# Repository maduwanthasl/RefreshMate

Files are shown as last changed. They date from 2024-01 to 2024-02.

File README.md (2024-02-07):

# Refreshmate: Automated Air Renewal and Freshener System for Public Toilets

## Overview
 🌬️ Introducing Refreshmate: Automated air renewal for public toilets. Gas sensors, microcontrollers, and a smart power mix tackle unpleasant odors, circulate fresh air, and add a pleasant aroma. Easy install, eco-friendly, optimized for performance. Completion accomplished for the Engineering Design Project in In21-S2-EN1190. 🚀

## Introduction:

- Refreshmate: Innovative project for automated air renewal and freshener in public toilets.
- Core components: Gas sensor, exhaust fan, and air freshener, powered by both electricity and batteries.
- Primary goal: Autonomously detect and eliminate unpleasant odors, improving air quality.
- Meticulous layout procedure: Careful component selection, testing, and systematic generation for optimal performance.
- Final product features: Easy installation, operation, and maintenance with minimal energy consumption, emphasizing environmental friendliness.

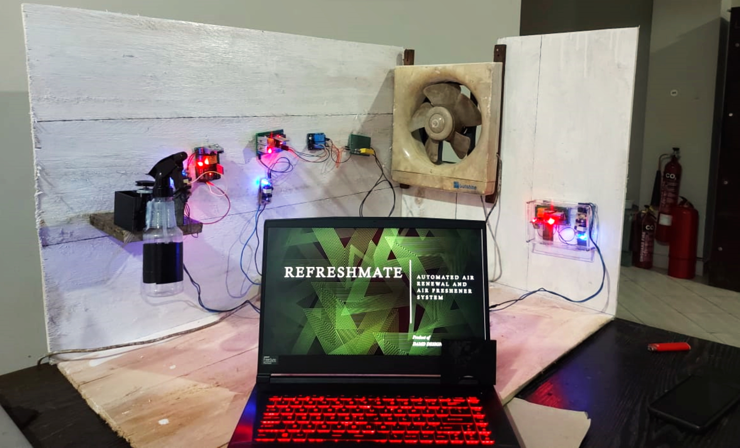
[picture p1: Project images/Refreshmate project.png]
Project Image


## How Rereshmate Works:

[Refreshmate Project Explain](https://github.com/maduwanthasl/RefreshMate/assets/107339150/9a8a3949-62f4-4360-bf2a-769d5a35e4b5)

**Modules:**
- We utilize three primary modules: the sensor module, the air freshener module, and the fan module.

**Gas Sensor Reading:**
- The gas sensor reads the air quality value in the restroom environment.

**ATTiny85 Processing:**
- The ATTiny85 microcontroller (in the sensor module) processes the data based on the air quality value.

**Data Transmission via HC-05 Bluetooth Module:**
- Using the HC-05 Bluetooth module, the processed data is transmitted to the air freshener and fan modules.

**ESP01 Module Data Processing:**
- The ESP01 modules in the air freshener and fan modules receive and process the transmitted data.

**Exhaust Fan Operation:**
- The exhaust fan is activated to expel dirty air rapidly in response to the processed data.

**Air Freshener Activation:**
- After a brief delay, the air freshener module is triggered, releasing a pleasant aroma into the restroom.

## Why I Chose These Components:

- Advanced Gas Sensing: Refreshmate employs a cutting-edge MQ135 gas sensor, swiftly identifying NH3 (ammonia) and demonstrating sensitivity to various other gases in the restroom environment. [Read datasheet](https://github.com/maduwanthasl/RefreshMate/blob/main/Datasheets/SNS-MQ135.pdf)
- Intelligent Microcontroller Control: The system strategically utilizes the compact ATTiny85 microcontroller for processing gas sensor data. The choice of ATTiny85, with its compact size and 8 pins, aligns seamlessly with project guidelines, allowing for a reduction in product size and cost. [Read datasheet](https://github.com/maduwanthasl/RefreshMate/blob/main/Datasheets/Atmel-2586-AVR-8-bit-Microcontroller-ATtiny25-ATtiny45-ATtiny85_Datasheet.pdf)
- Selection of ESP01 Module: To the air freshener module and fan module, the ESP01 Tiny Arduino-based module is seamlessly integrated. This compact and cost-effective module not only aligns with the project's space and budget considerations but also lays the foundation for future enhancements. The ESP01 facilitates the potential integration of server-based data transmission, allowing users to monitor and analyze air quality data remotely. Furthermore, the inclusion of WiFi capabilities opens the door to user-friendly features, enabling remote on/off control via WiFi, enhancing the overall accessibility and functionality of the Refreshmate system.[Read datasheet](https://github.com/maduwanthasl/RefreshMate/blob/main/Datasheets/esp01.pdf)
- Selection of HC-05 Bluetooth Module: I chose the HC-05 Bluetooth module for all modules due to its user-friendly attributes, including a small number of pins and ease of control.[Read datasheet](https://github.com/maduwanthasl/RefreshMate/blob/main/Datasheets/HC-05%20Datasheet.pdf)

## What I Did in This Project:
🛠️ During this project, I was responsible for:

- Defining clear objectives for Refreshmate, outlining the goals and desired outcomes.
- Conducting thorough research and planning to understand the requirements and challenges of automated air renewal in public toilets.
- Selecting appropriate components based on performance, compatibility, and cost considerations.
- Performing simulations in Proteus to validate the functionality and performance of the system before implementation.
- Testing individual components and subsystems to ensure functionality and reliability.
- Designing PCBs using Altium Designer for efficient integration and layout of electronic components.
- Creating enclosure designs in SolidWorks to house the electronic components securely and aesthetically.
- Testing the system with Arduino Uno microcontroller to verify compatibility and functionality.
- Soldering electronic components onto PCBs to assemble the hardware modules.
- Conducting rigorous testing of PCBs to identify and rectify any issues or defects.
- Implementing improvements based on testing results and feedback to enhance system performance and reliability.
- Finalizing the design and configuration of Refreshmate for deployment in real-world settings.
- Testing the system with prototype boards to evaluate performance under realistic conditions.
- Designing circuit diagrams to document the electrical connections and configurations of the system.
- Demonstrating the functionality of Refreshmate using Arduino Uno microcontroller for validation and verification.
- Testing and debugging the system to address any issues or errors and ensure smooth operation.

## Block diagram of systems
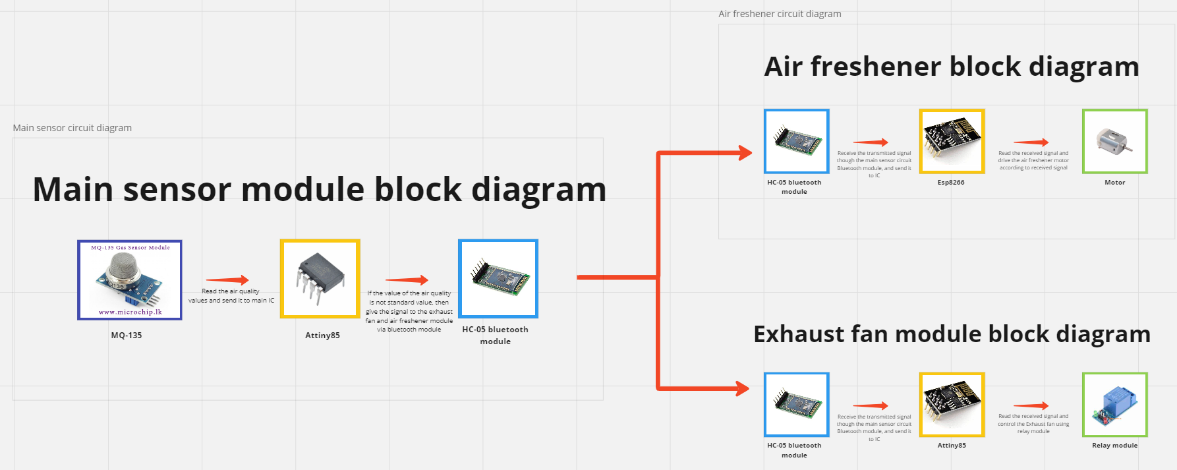
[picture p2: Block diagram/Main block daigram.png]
Block diagram


## Submodules, Circuits, and Tasks:

1. **Sensor Module:**
   - The sensor module is responsible for reading data from the environment to assess air quality.

2. **Air Freshener Module:**
   - Upon receiving data, the air freshener module activates with a slight delay. It adjusts the release of air freshener liquid based on the detected level of pollutants. Higher levels of pollutants trigger a stronger release of the air freshener.

3. **Fan Module:**
   - The fan module responds to received data by activating the fan. It adjusts the fan speed based on the detected level of pollutants. Higher levels of pollutants result in a higher fan speed, while lower levels lead to a slower fan speed.

## Hardware Specifications

| Component | Specification |
|---|---|
| Gas Sensor | MQ135 |
| Exhaust Fan | AC Cooling Fan 8025 |
| Air Freshener | Airwick Air Freshener Spray 475ml |
| DC Power Supply | 3.7V LiPo Batteries (x3) and 9V Batteries |
| AC Power Supply | SMPS Power supply 12V |
| Bluetooth Modules | HC-05 (x6) |
| Microcontroller | ATTiny85 |
| ESP Modules | ESP01 (x2) |
| Motor | N/A |
| Relay Modules | 9V Relay Modules (x2) ,Two chaneel relay module |
| Heat Sinks | Heat Sinks (x4) |
| Other Components | Resistors, Capacitors, LEDs, Connecting Wires, Diodes, Plug Coverings, and more |

## Software Specifications

- Solidworks
- Altium Designer
- Proteus
- Arduino IDE

## PCB Designs

### Sensor module

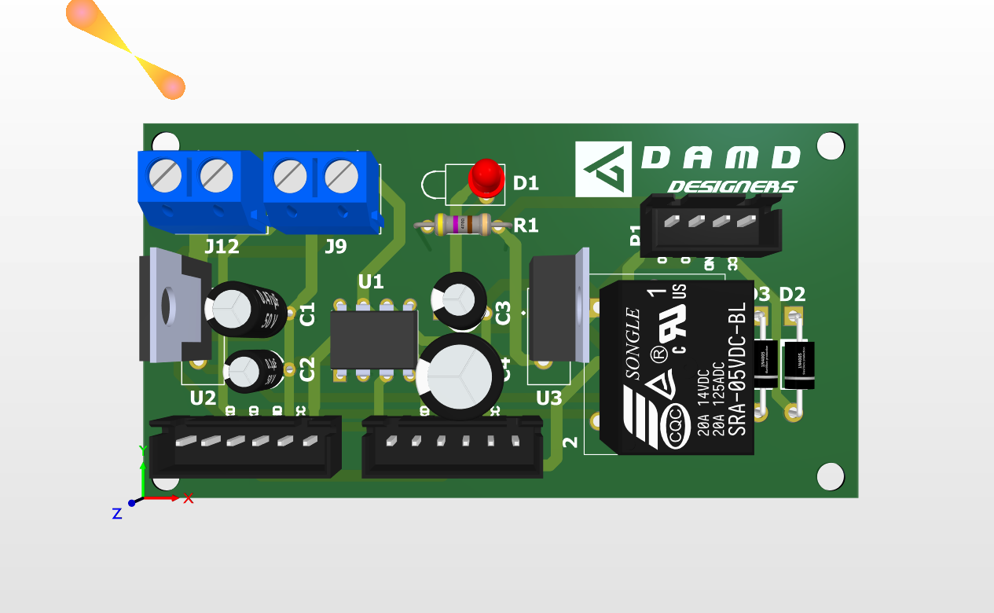
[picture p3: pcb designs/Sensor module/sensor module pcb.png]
Sensor module 3D
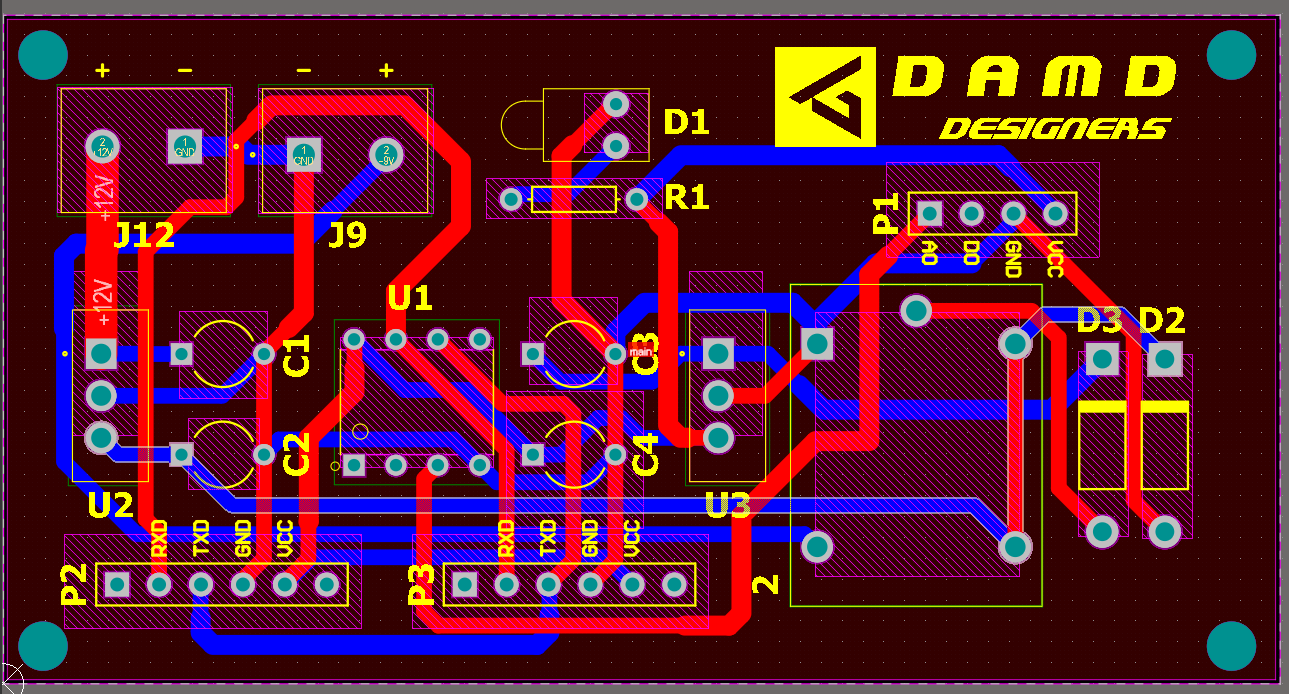
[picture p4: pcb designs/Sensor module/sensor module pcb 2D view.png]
Sensor module 2D
|  |  |
|---|---|
| Sensor module 3D | Sensor module 2D |

### Air freshner and Fan module
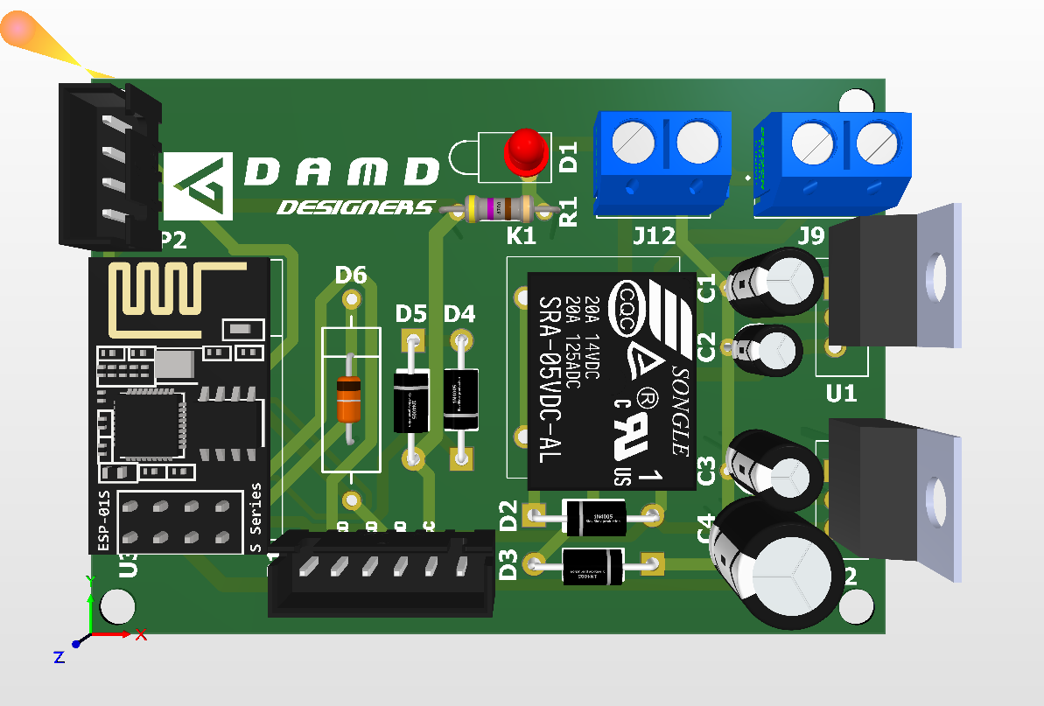
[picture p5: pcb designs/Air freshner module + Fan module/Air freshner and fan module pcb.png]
Air freshner module 3D
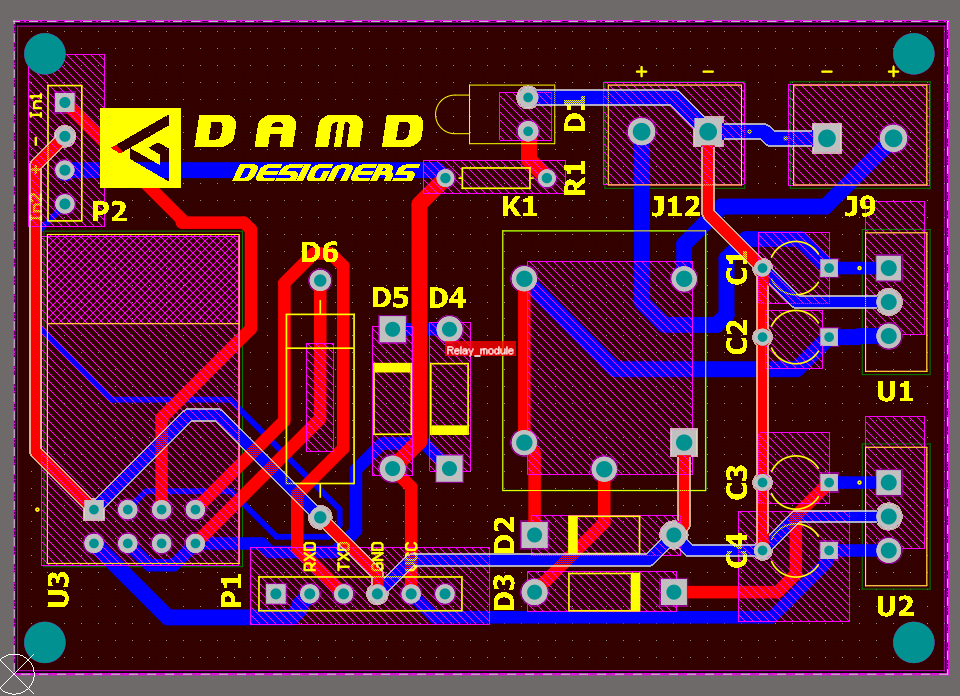
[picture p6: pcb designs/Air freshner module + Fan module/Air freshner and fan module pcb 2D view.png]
Air freshner module 2D
|  |  |
|---|---|
| Air freshner module 3D | Air freshner module 2D |

## Enclosure Design

### Sensor module
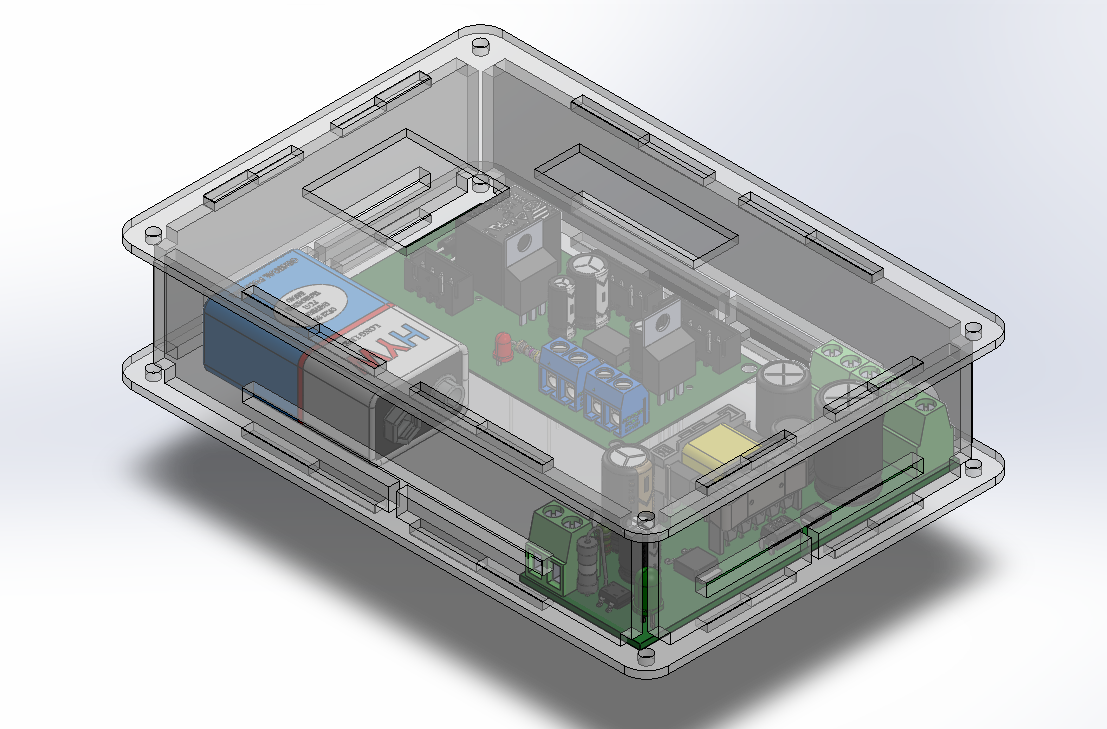
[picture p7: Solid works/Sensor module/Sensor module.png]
Sensor module 3D
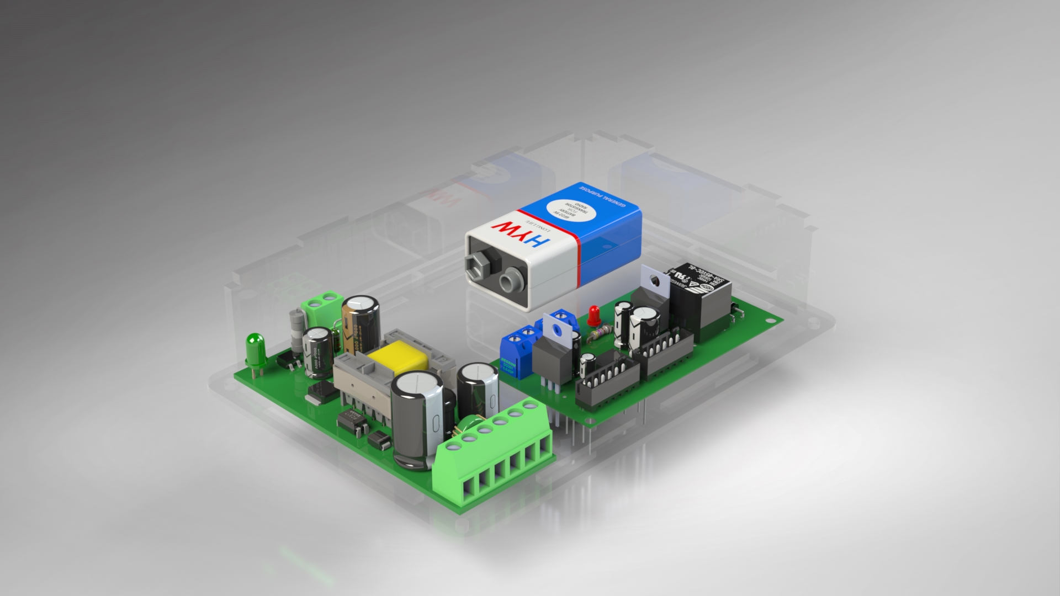
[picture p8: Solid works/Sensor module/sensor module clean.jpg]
|  |  |
|---|---|
| Sensor module 3D | Render image |

### Air Freshner module

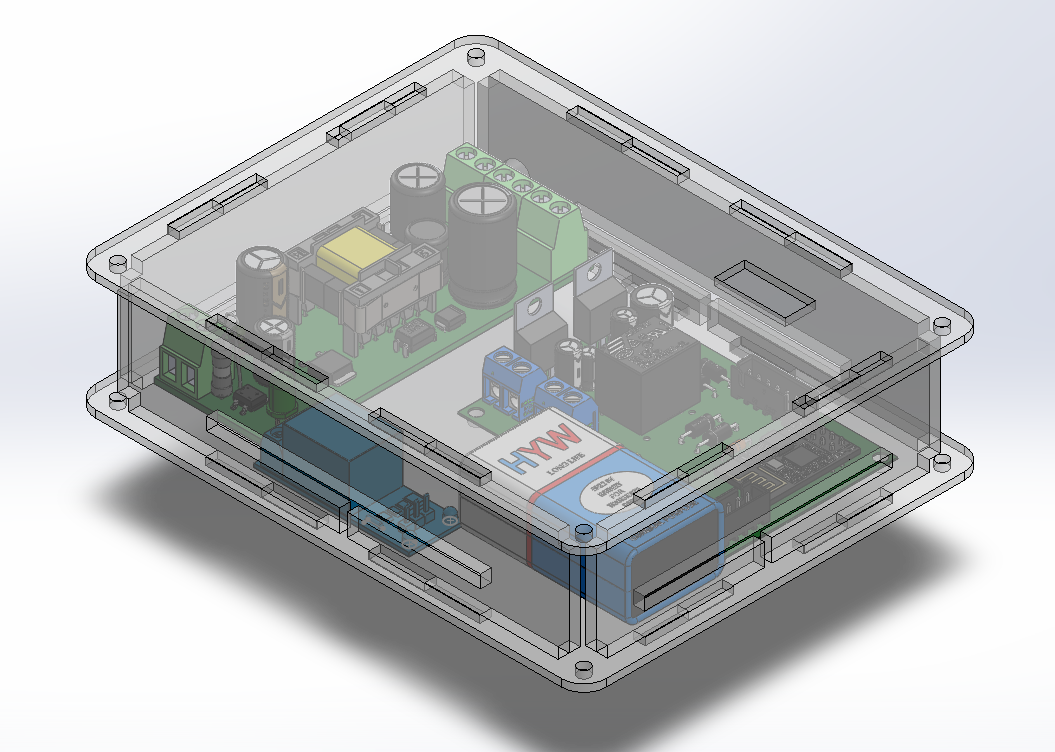
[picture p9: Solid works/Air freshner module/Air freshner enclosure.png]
Air Freshner module
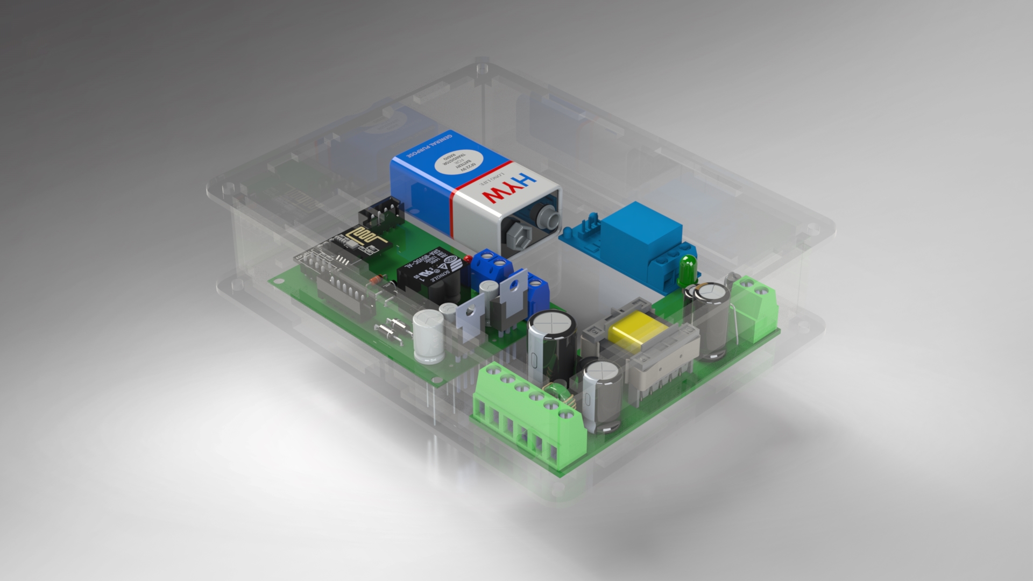
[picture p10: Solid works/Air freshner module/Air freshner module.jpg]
| |  |
|---|---|
| Air Freshner module | Render image |

## For More Information About Refreshmate

- Final Project Report: [Project Report](https://raw.githubusercontent.com/maduwanthasl/RefreshMate/3827d9fda2ea041df4310b1e1ae76f7727d4d3ec/Project%20proposal/DAMD%20Designers_Final%20project%20report.pdf)
- Refreshmate Project Explanation Video: [Explaining Video](https://drive.google.com/file/d/1oDDOuYQFnANiH_yXHOmqUqlNW3DxZMKs/view?usp=sharing)

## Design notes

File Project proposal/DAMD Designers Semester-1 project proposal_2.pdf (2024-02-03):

### PROJE CT PROPOSAL

# RefreshMate

## Automated air renewal and air fresher system

## April 5, 2023

Prepared by:
DAMD Designers :-
D.M.P.C. Dissanayaka
U.M.Y.B. Alahakoon
L.H.H.Maduwantha
D.M.T.K.R. Dassanayake

Supervised by:
Prof. Ajith pasqual

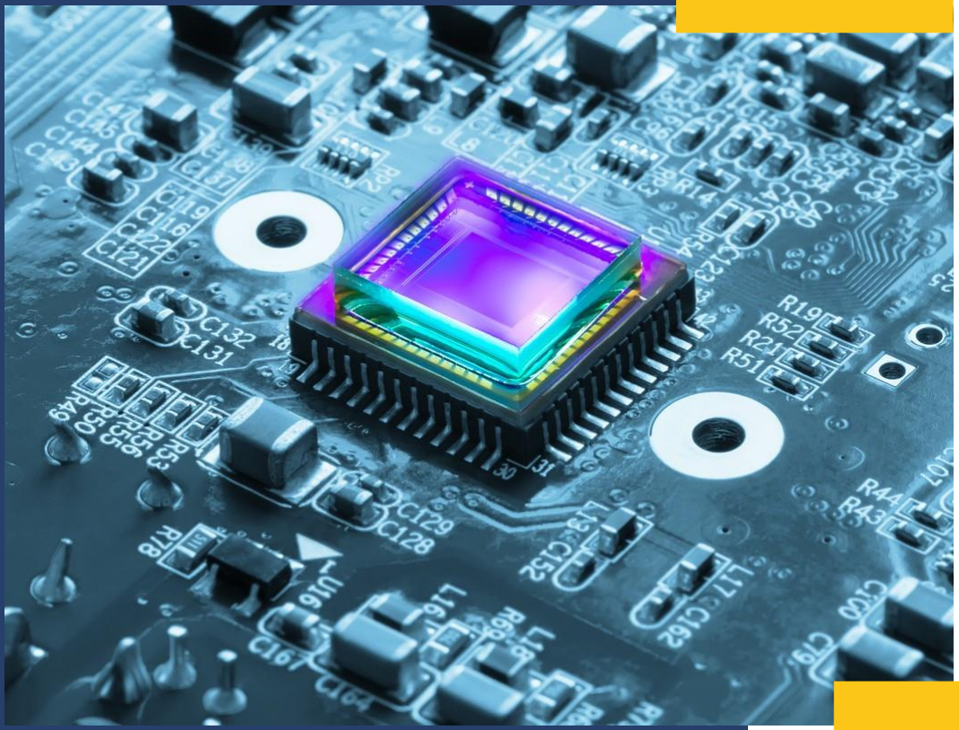
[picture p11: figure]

IN TRODU CT ION

The proposed design project aims to develop an automated air renewer and air fresher system for public toilets and washrooms. The system will be designed to improve the air quality inside public toilets by automatically detecting and eliminating unpleasant odors. The system will also work to keep the air fresh and pleasant by continuously circulating fresh air. Our suggest system will be easy to install and operate, and will require minimal maintenance. This project aims to enhance the overall user experience in public toilets and promote better hygiene practices.

OBJE CT IVES

The proposed system will be scalable and can be installed in different types of public toilets, including schools, universities, shopping malls, train stations, and other public areas with high foot traffic.
The implementation of this proposed design project will provide numerous benefits, including improved air quality, better hygiene, and enhanced user experience for public toilet users.
The system will be powered by electricity and will be designed to consume minimal energy, making it cost-effective and environmentally friendly.

M E T H O D O L O G Y

1. Install a gas sensor in the public space to monitor the air quality. The gas sensor should be able to detect common pollutants, such as ammonia, carbon dioxide, alcohol, Benzene, smoke and particulate matter.
2. Set the gas sensor to monitor the air quality at regular intervals. This will ensure that any changes in the air quality are detected quickly and automatically.
3. When the gas sensor detects a decrease in air quality, activate a system that recycles fresh air throughout the public space. This is done using a exhaust fan that draws in fresh air from outside and circulates it throughout the space.
4. Once the air has been refreshed, release an air freshener to provide a pleasant aroma. Choose an air freshener that is free from harmful chemicals and has a scent that is appropriate for the public space.

C ON CL U SI ON

Our proposal has a sample product that is built and is suitable for small-sized bathrooms. Similar methodology can be used for larger public bathrooms, but the unit's capacity must be sufficiently increased, and a pressurized air freshener system must be implemented.
Overall, we believe that this project has the potential to greatly benefit both individuals and communities, and we look forward to exploring its implementation in greater detail.

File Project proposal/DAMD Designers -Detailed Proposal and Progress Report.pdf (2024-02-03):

# EN1190 Engineering Design Project

# Project progress report

# DAMD Designers

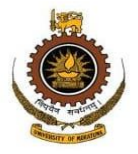
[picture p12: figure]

# ReFreshmate

# (Automated air renewal and air fresher system)

Prepared by:

D.M.P.C. Dissanayaka : 210140P

U.M.Y.B. Alahakoon | : 210027C
L.H.H. Maduwantha | : 200370K

D.M.T.K.R. Dassanayake: 210095F

Table of Contents | page no
01. Abstract | 03
02. Problem description, relevance, and justification | 04
03. Technical specifications | 05
04. Product architecture with technical viability | 06
05. Initial sketches and finalized product architecture | 07
06. Marketing, Sales, and Aftercare | 08
07. Limitations, future plans and conclusion | 09
08. Project budget, and Task allocation | 10

Abstract….

The proposed project, Refreshmate, aims to develop an automated air renewal and air freshener system for public toilets and washrooms. The system will be designed to improve the air quality in public bathrooms by automatically detecting and eliminating unpleasant odors. The proposed system includes a gas sensor, an exhaust fan, and an air freshener connected via a microcontrollers and powered by electricity and batteries. The system will detect and eliminate unpleasant odors quickly and effectively, while also circulating fresh air and providing a pleasant aroma. The layout procedure will involve careful selection of components, testing, and generation to ensure the most

appropriate performance. Our final product will be easy to install,

## operate, maintain with minimal energy consumption, and be

environmentally friendly.

# Problem Description Relevance, and Justification

# Problem description and relevance:

- Public toilets are notorious for creating unpleasant odors due to the accumulation of bacteria and other pollutants. These odors not only make users uncomfortable, but also pose health risks by spreading airborne infections.
- Currently, there are few solutions to this problem. The most common method is to use mechanical air fresheners or manual deodorants. However, these solutions are often ineffective and short-lived, requiring frequent replacement and maintenance.
- Improving air quality and promoting healthy hygiene practices in public toilets and washrooms may have a positive effect on public health and well-being. By decreasing the spread of harmful bacteria and viruses, those spaces may be made safer and more welcoming for all users.

# Problem justification:

Our team conducted informal interviews with users of public toilets to gather information about their experiences with air quality and odors. From these conversations, the team observed that unpleasant odors were a common problem that negatively impacted users' experiences and sometimes caused them to avoid using public washrooms altogether. Observation results can be represented in following pie chart.

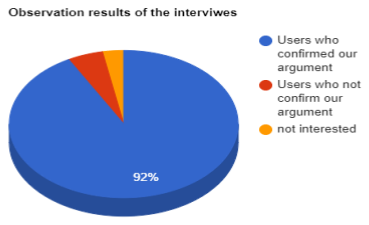
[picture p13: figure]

# Technical Specifications

We have planned to demonstrate a scaled down version of the original application. Based on the experience of the small-scale demonstration, we can describe the practical toilet conditions that the proposed system aims to address. The following chart shows the components required for our scaled down version of the final product.

Characteristics | Specifications
Ammonia sensor | MQ135
Exhaust fan | AC Cooling fan 8025
Air freshener | Airwick Air Freshener Spray 475ml
DC power supply | 9V batteries × 3
Bluetooth modules | HC-05 × 3
Enclosure box | 1m × 1m × 1m cardboard box
Microcontroller | ATTiny85 × 3
Motor | 130 Toy Motor
Crystal | Crystal Oscillator 16MHz
Switch | Push button switches On/Off rocket switches
Other required components | Resistors Capacitors Connecting wires Relay module Transistors Diodes LEDs

# Product Architecture with Technological Viability

# Block diagram of systems

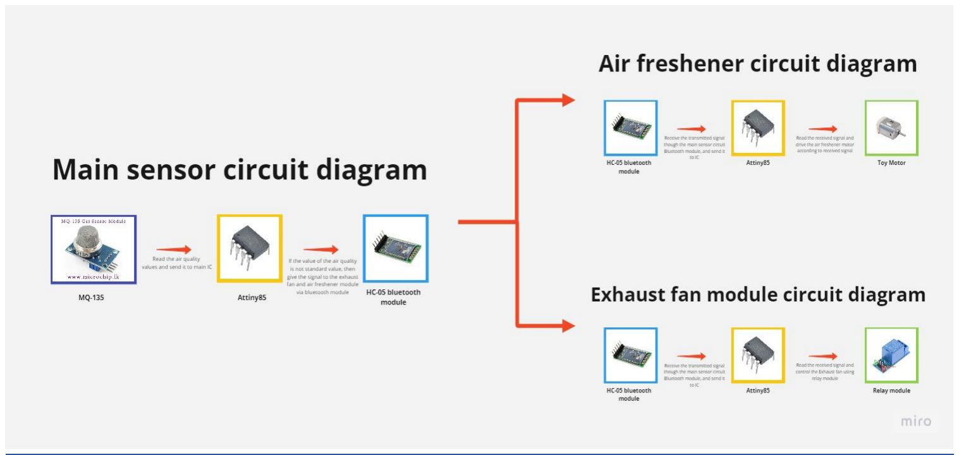
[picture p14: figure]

## Technical viability

- Main sensor circuit unit: Our selected gas sensor (MQ135) should be able to detect common pollutants and changes quickly and accurately in air quality, triggering the exhaust fan and air purifier to maintain optimal air quality and deliver a pleasant aroma. The sensor will be able to send signals to the microcontroller block. So, if the value of the air quality is not within the standard value range, it gives a signal to the exhaust fan and the air freshener module through the Bluetooth module. This system is powered by a 9V battery.

## - Use of an exhaust fan module to circulate fresh air: The AC fan will be

activated by the microcontroller using a relay module when Bluetooth module receives the transmitted signal through the main sensor circuit.

- Air Freshener system: This system will include an air freshener that releases a pleasant scent after the air has been refreshed by the exhaust fan. When transmitted signal received to the Bluetooth module from the main sensor and it sends that signal to an IC. The IC will read the received signal and drive the toy motor in the air freshener according to the received signal. This system is powered by a 9V battery.

# Initial and Finalized Sketches of the

Product.

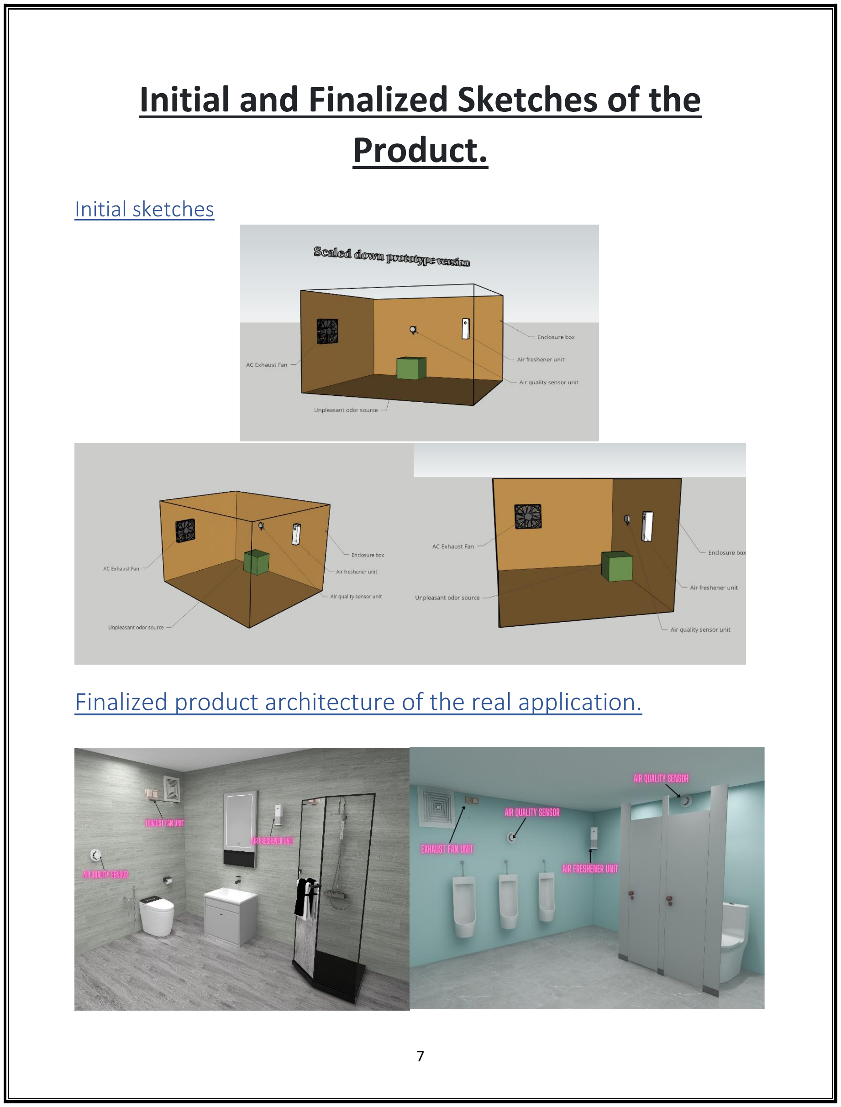
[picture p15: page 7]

## Initial sketches

Finalized product architecture of the real application.

# Marketing, Sales, and Aftercare

## Marketing targets

- According to our informal interviews, the main sources of being uncomfortable for prospective customers are unpleasant odors, poor air quality, and hygiene concerns in public restrooms. Our product addresses these issues by automatically detecting and eliminating unpleasant odors and continuously circulating fresh air, providing a pleasant and hygienic restroom experience.
- Before introducing our automated air renewal and fresher system to the market, we conducted extensive market research to understand the target market and identify potential customers. Our research showed that public toilets and washrooms in high traffic areas such as shopping malls, bus and train stations, schools, universities, and hospitals are the most suitable locations for our product.

## Pricing Strategy and Sales

- While taking into consideration the specific characteristics and advantages of the product, our pricing strategy is expected to stay competitive.
- Our pricing strategy is based on the cost of materials, labor, and manufacturing, as well as a competitive analysis of similar products. We will price our product competitively while still maintaining a reasonable profit margin. Because we are planning to make this product in a large-scale cost of manufacturing can be reduced by a large margin.
- We project that we can sell our product at a price point of Rs.8000/= to Rs.12000/= per unit.

## Aftercare

- To ensure customer satisfaction and, we have planned to develop an after-sale service plan that includes a warranty period, technical support, and repair services. We will offer a one-year warranty on all parts and labor. If any issues arise during the warranty period, customers can contact our technical support team for assistance. If a product needs repair after the warranty period, we will offer repair services at a reasonable cost.
- To ensure the system is functioning at optimal capacity, regular maintenance check-ups are planned to be scheduled every 6 months.
- Regularly collecting and analyzing customer feedback highlights areas for development and making sure that our product’s after-sale support strategy satisfies consumer needs.

# Limitations, Future Works and Conclusion

## Limitations and future works

- It is important to consider some limitations despite the significant potential of the proposed system. For example, the proposed system may not be suitable for very large public bathrooms without significant modifications such as installing more sensors and air freshener modules, as the unit's capacity may not be sufficient. The effectiveness of the system may be limited as it is designed to detect common pollutants like ammonia, carbon dioxide, alcohol, Benzene, smoke, and particulate matter but may not have the ability to detect all potential pollutants. Hence, further research and development may be required to expand the system's pollutant detection capabilities. Additionally, further research and development may be required to expand the system's pollutant detection capabilities.
- Expanding the proposed system to include additional features like real-time monitoring of air quality and remote-control capabilities is a potential area for future work. The system could also be integrated with smart building systems to enable even greater efficiency and control. In addition, the promotion of improved indoor air quality and hygiene could be extended to other settings such as homes and offices by adapting the proposed system.

## Conclusion

The proposed system is scalable and can be installed in different types of public toilets. It will provide numerous benefits, including improved air quality, better hygiene, and enhanced user experience for public toilet users. It is cost-effective and environmentally friendly as it will consume minimal energy. The project's technical feasibility, product architecture, initial and finalized sketches of the product enclosures, marketing, sales, and after-sale service considerations, and project budget with bill of quantities have been discussed in detail. The task allocation among the group members has also been outlined.

Overall, this project has the potential to greatly benefit both individuals and communities, and we look forward to exploring its implementation in greater detail. While there may be limitations and challenges, we believe that with the right approach, this project can achieve its goals and make a positive impact on public health and hygiene. Further work will be needed to optimize the system and make it widely accessible.

# Project Budget, and Task Allocation

# Bill Of Quantities

Item | Quantity | Unit price Rs. /= | Total Rs/=
MQ135 Ammonia sensor | 1 | 540 | 540
Exhaust fan | 1 | 780 | 780
Airwick Air Freshener Spray 450ml | 1 | 740 | 740
Attiny85 microcontrollers | 3 | 835 | 2505
Hc-05 Bluetooth module | 3 | 500 | 1500
9V Batteries | 3 | 160 | 480
130 Toy Motor | 1 | 50 | 50
Crystal Oscillator 16MHz | 1 | 40 | 40
Relay Module | 1 | 180 | 180
PCB design cost | 3 | 500 | 1500
Enclosure material cost | - | 1000 per 100g | 1000
Resisters, Capacitors, connecting wires and other | - | - | 200
Total budget | Rs. 9515/=

## Task Allocation among group members

Roles and responsibilities of each group member. To ensure efficient and effective project execution, we have assigned specific roles and responsibilities to each group member.
L.H.H. Maduwantha | Solid works and System development
D.M.P.C. Dissanayaka | Altium and PCB Designing
U.M.Y.B. Alahakoon | Microcontroller programming and Research planning
D.M.T.K.R. Dassanayake | 3D Modeling, Enclosure Designing and Market Research Management

********

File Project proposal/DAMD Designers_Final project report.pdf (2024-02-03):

1 | P a g e

## EN1190 Engineering Design Project

## Final Project Report

# DAMD Designers

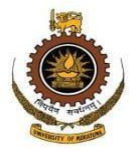
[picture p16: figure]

# ReFreshmate

## (Automated air renewal and air fresher system)

Prepared by:

D.M.P.C. Dissanayaka : 210140P

U.M.Y.B. Alahakoon | : 210027C
L.H.H. Maduwantha | : 200370K

D.M.T.K.R. Dassanayake: 210095F

2 | P a g e

# Table of Contents

Content | Page no
01. Abstract | 03
02. Problem description, relevance, and justification | 04
03. Technical specifications | 05
04. Product architecture with technical feasibility | 06
05. Prototype sketches and finalized product architecture | 07
06. Enclosure (Solid Works) and PCB (Altium) design | 08
07. Marketing and Sales | 09
08. Limitations and future plans | 10
09. Bill of Quantities | 11
10. Task Allocation | 12
11. Conclusion | 13

3 | P a g e

Abstract….

The proposed project, Refreshmate, aims to develop an automated air renewal and air freshener system for public toilets and washrooms. The system will be designed to improve the air quality in public bathrooms by automatically detecting and eliminating unpleasant odors. The proposed system includes a gas sensor, an exhaust fan, and an air freshener connected via a microcontroller and powered by electricity and batteries. The system will detect and eliminate unpleasant odors quickly and effectively, while also circulating fresh air and providing a pleasant aroma. The layout procedure will involve careful selection of components, testing, and generation to ensure the most

appropriate performance. Our final product will be easy to install,

### operate, maintain with minimal energy consumption, and be

environmentally friendly.

4 | P a g e

# Problem Description Relevance, and Justification

## Problem description and relevance:

- Public toilets are notorious for creating unpleasant odors due to the accumulation of bacteria and other pollutants. These odors not only make users uncomfortable, but also pose health risks by spreading airborne infections.
- Currently, there are few solutions to this problem. The most common method is to use mechanical air fresheners or manual deodorants. However, these solutions are often ineffective and short-lived, requiring frequent replacement and maintenance.
- Improving air quality and promoting healthy hygiene practices in public toilets and washrooms may have a positive effect on public health and well-being. By decreasing the spread of harmful bacteria and viruses, those spaces may be made safer and more welcoming for all users.

## Problem justification:

Our team conducted informal interviews with users of public toilets to gather information about their experiences with air quality and odors. From these conversations, the team observed that unpleasant odors were a common problem that negatively impacted users' experiences and sometimes caused them to avoid using public washrooms altogether. Observation results can be represented in the following pie chart.

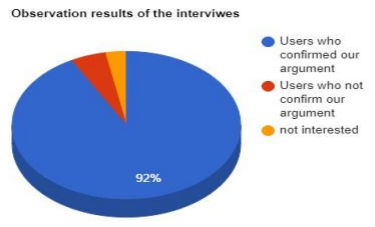
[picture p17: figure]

5 | P a g e

# Technical Specifications

We have demonstrated a scaled down version of the original application. Based on the experience of the small-scale demonstration, we can describe the practical toilet conditions that the proposed system aims to address. The following chart shows the components required for our scaled down version of the final product.

Characteristics | Specifications
Ammonia sensor | MQ135
Exhaust fan | AC Cooling fan 8025
Air freshener | Airwick Air Freshener Spray 475ml
DC power supply | 3.7 LiPo batteries × 3 and 9V batteries
Bluetooth modules | HC-05 × 2
Enclosure box | Corner of 3× 2× 2 wood box (3 sides)
Microcontroller | ATTiny85 and ESP02 × 2
Motor | Motor
Relay modules | 9V Relay modules × 2
Heat sinks | Heat sinks × 2
Other required components | Resistors Capacitors Connecting wires Relay module Diodes LEDs Plug coverings and other

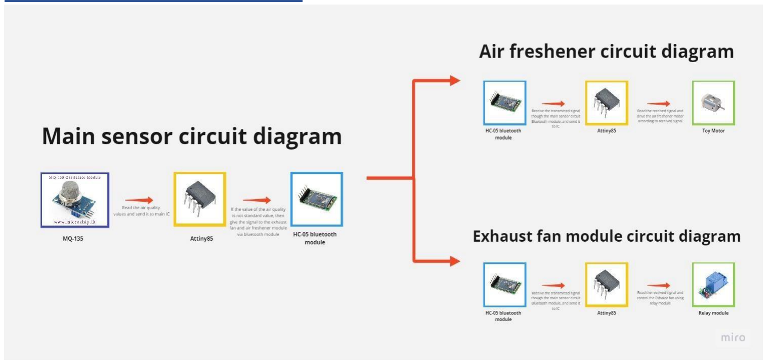
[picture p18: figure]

6 | P a g e

# Product Architecture with Technological Viability

## Block diagram of systems

### Technical feasibility

- Main sensor circuit unit: Our selected gas sensor (MQ135) should be able to detect common pollutants and changes quickly and accurately in air quality, triggering the exhaust fan and air purifier to maintain optimal air quality and deliver a pleasant aroma. The sensor will be able to send signals to the microcontroller block. So, if the value of the air quality is not within the standard value range, it gives a signal to the exhaust fan and the air freshener module through the Bluetooth module. This system is powered by a 9V battery or can be powered by AC supply.
- Use of an exhaust fan module to circulate fresh air: The AC fan will be activated
by the microcontroller using a relay module when Bluetooth module receives the transmitted signal through the main sensor circuit. (Our system can by without this module or without this).
- Air Freshener system: This system will include an air freshener that releases a pleasant scent after the air has been refreshed by the exhaust fan. When transmitted signal received to the Bluetooth module from the main sensor and it sends that signal to an IC. The IC will read the received signal and drive the toy motor in the air freshener according to the received signal. This system is powered by 3 LiPo batteries or Ac Supply.

# Prototype and Finalized Sketches of the

Product.

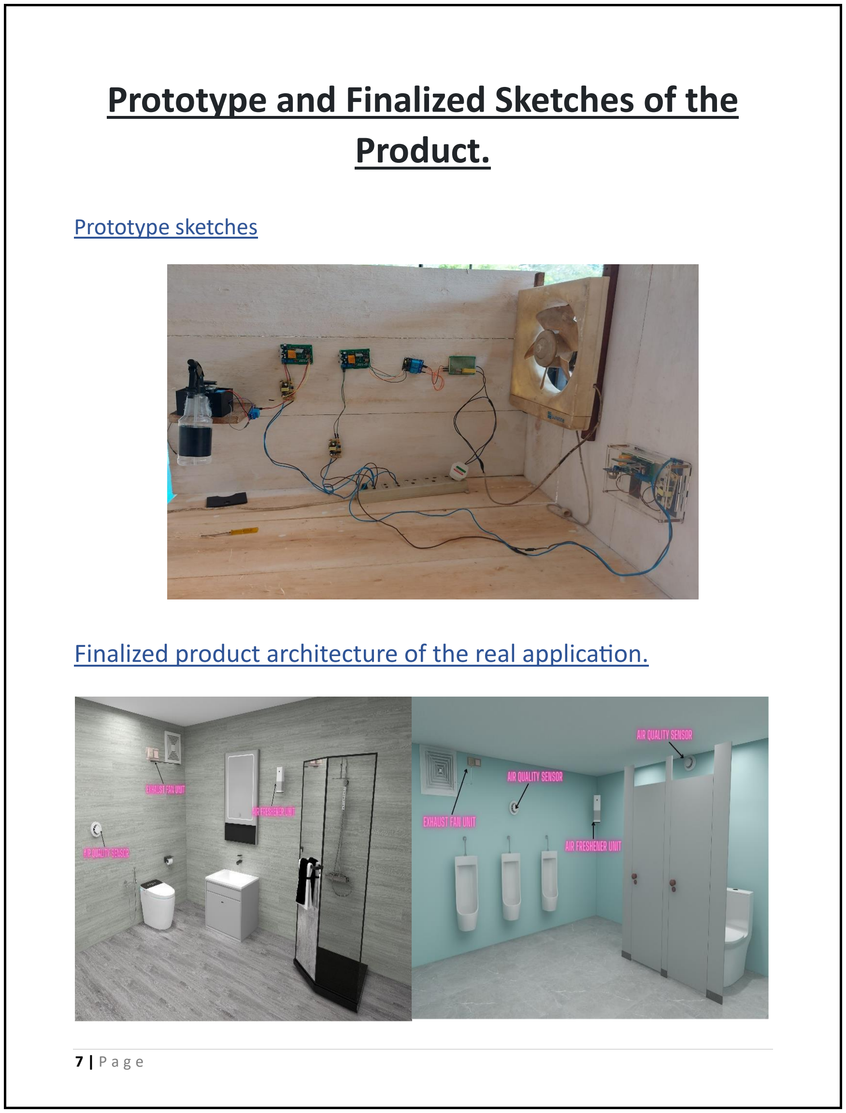
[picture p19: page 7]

7 | P a g e

### Prototype sketches

Finalized product architecture of the real application.

# Solid Works (Enclosure) and Altium(PCB) Designs

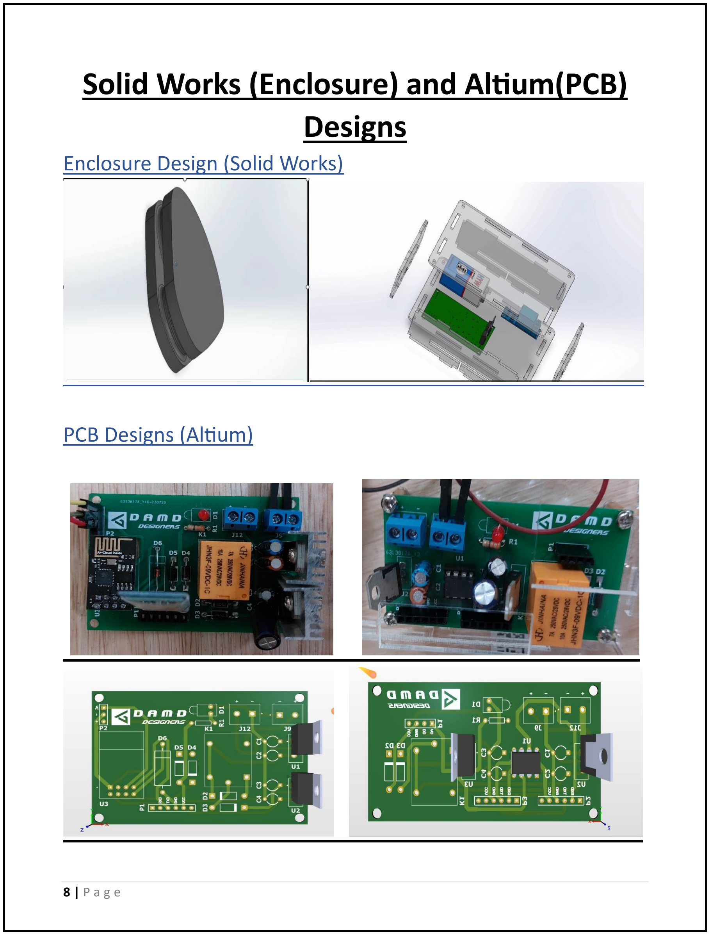
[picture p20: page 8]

8 | P a g e

## Enclosure Design (Solid Works)

## PCB Designs (Altium)

9 | P a g e

# Marketing and Sales

## Marketing targets

- According to our informal interviews, the main sources of being uncomfortable for prospective customers are unpleasant odors, poor air quality, and hygiene concerns in public restrooms. Our product addresses these issues by automatically detecting and eliminating unpleasant odors and continuously circulating fresh air, providing a pleasant and hygienic restroom experience.
- Before introducing our automated air renewal and fresher system to the market, we conducted extensive market research to understand the target market and identify potential customers. Our research showed that public toilets and washrooms in high traffic areas such as shopping malls, bus and train stations, schools, universities, and hospitals are the most suitable locations for our product.

## Pricing Strategy and Sales

- While taking into consideration the specific characteristics and advantages of the product, our pricing strategy is expected to stay competitive.
- Our pricing strategy is based on the cost of materials, labor, and manufacturing, as well as a competitive analysis of similar products. We will price our product competitively while still maintaining a reasonable profit margin. Because we are planning to make this product in a large-scale cost of manufacturing can be reduced by a large margin.
- We project that we can sell our product at a price point of Rs.18000/= to Rs.21000/= per unit. (Without Exhaust fan or with the exhaust fan)

10 | P a g e

# Aftercare, Limitations and Future Works

## Aftercare

- To ensure customer satisfaction and, we have planned to develop an after-sale service plan that includes a warranty period, technical support, and repair services. We will offer a one-year warranty on all parts and labor. If any issues arise during the warranty period, customers can contact our technical support team for assistance. If a product needs repair after the warranty period, we will offer repair services at a reasonable cost.
- To ensure the system is functioning at optimal capacity, Sensor replacement is done in 1 year and battery is rechargeable, or you can directly plug in our system to 230V AC source. Our team do routine maintenance checkups every monthly.
- Regularly collecting and analyzing customer feedback highlights areas for development and making sure that our product’s after-sale support strategy satisfies consumer needs.

## Limitations and future works

- It is important to consider some limitations despite the significant potential of the proposed system. For example, the proposed system may not be suitable for very large public bathrooms without significant modifications such as installing more sensors and air freshener modules, as the unit's capacity may not be sufficient. The effectiveness of the system may be limited as it is designed to detect common pollutants like ammonia, carbon dioxide, alcohol, Benzene, smoke, and particulate matter but may not have the ability to detect all potential pollutants. Hence, further research and development may be required to expand the system's pollutant detection capabilities. Additionally, further research and development may be required to expand the system's pollutant detection capabilities.
- Expanding the proposed system to include additional features like real-time monitoring of air quality and remote-control capabilities is a potential area for future work. The system could also be integrated with smart building systems to enable even greater efficiency and control.

11 | P a g e

# Bill Of Quantities

Item | Quantity | Unit Price RS/=

## Total price

Rs/=

MQ135 gas sensor | 1 | 475 | 475
SMPC12V Power supplies | 1 | 400 | 400

Airwick Air Freshener Spray
475ml
| 1 | 500 | 500
batteries | 3 | 800 | 2400
HC-05 Bluetooth modules | 2 | 520 | 1050
Attiny85 Microcontroller | 1 | 800 | 800
ESP01 Microcontroller | 2 | 600 | 1200
Motor | 1 | 520 | 520
9V Relay modules | 2 | 120+360 | 480
Heat sinks | 2 | 20 | 80
PCB Design cost | - | - | 4460

Enclosure
Design cost
- | - | 8500

Resisters, capacitors, LEDs, connecting wires and other

### TOTAL

1000

21865/=

12 | P a g e

# Task Allocation

Roles and responsibilities of each group member. To ensure efficient and effective project execution, we have assigned specific roles and responsibilities to each group member.

L.H.H. Maduwantha | Solid works and System development
D.M.P.C. Dissanayaka | Altium and PCB Designing
U.M.Y.B. Alahakoon | Microcontroller programming and Research planning
D.M.T.K.R. Dassanayake | 3D Modeling, Enclosure Designing and Market Research Management

13 | P a g e

# Conclusion |

The proposed system is scalable and can be installed in different types of public toilets. It will provide numerous benefits, including improved air quality, better hygiene, and enhanced user experience for public toilet users. It is cost-effective and environmentally friendly as it will consume minimal energy. The project's technical feasibility, product architecture, initial and finalized sketches of the product enclosures, marketing, sales, and after-sale service considerations, and project budget with bill of quantities have been discussed in detail. The task allocation among the group members has also been outlined.

Overall, this project has the potential to greatly benefit both individuals and communities, and we look forward to exploring its implementation in greater detail. While there may be limitations and challenges, we believe that with the right approach, this project can achieve its goals and make a positive impact on public health and hygiene. Further work will be needed to optimize the system and make it widely accessible.

******************

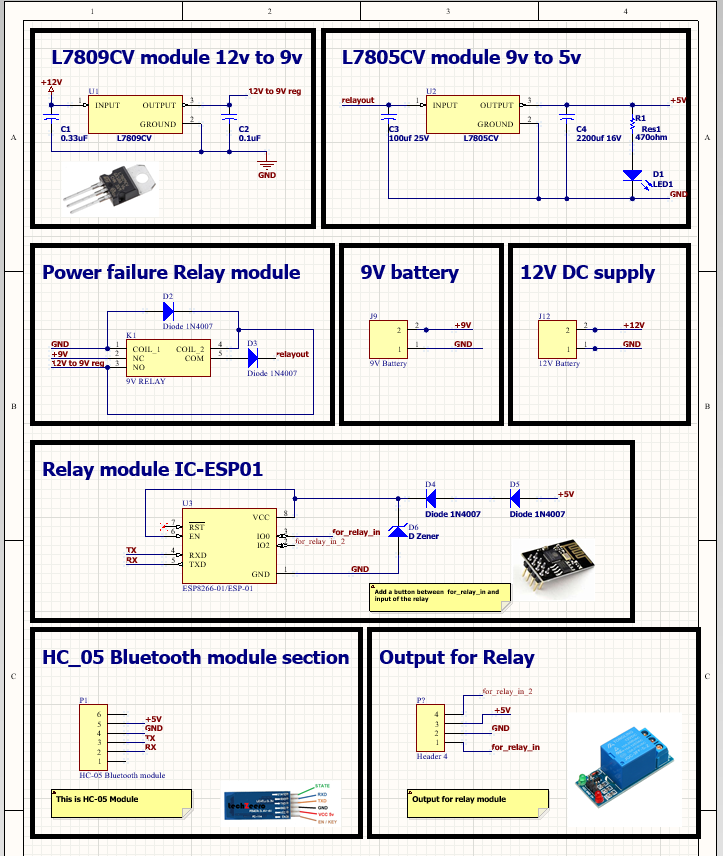
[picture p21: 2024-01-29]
Circuits & enclosures png/Air freshner and fan module schematic.png

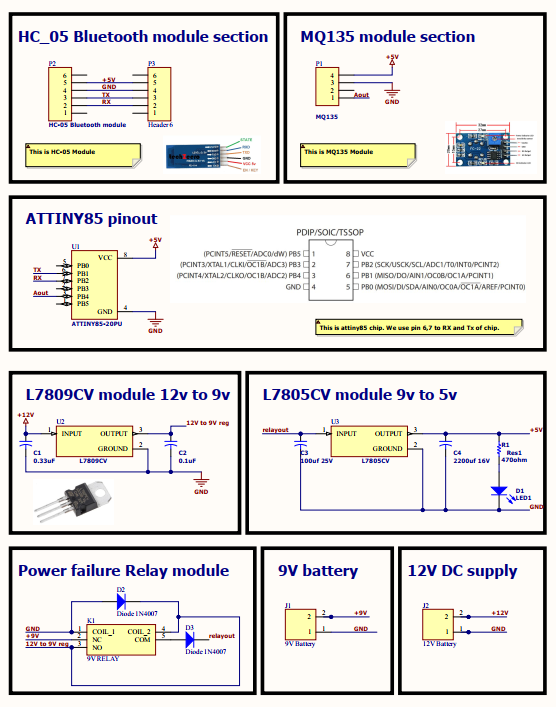
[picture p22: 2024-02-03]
Circuits & enclosures png/Sensor module schematic.png

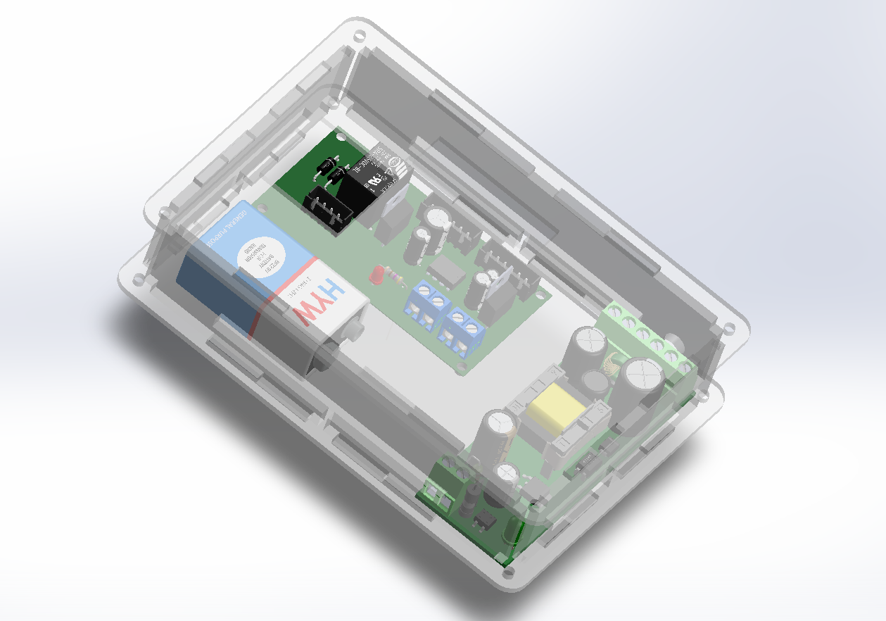
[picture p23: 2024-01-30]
Solid works/Sensor module/Sensor module_3D.png

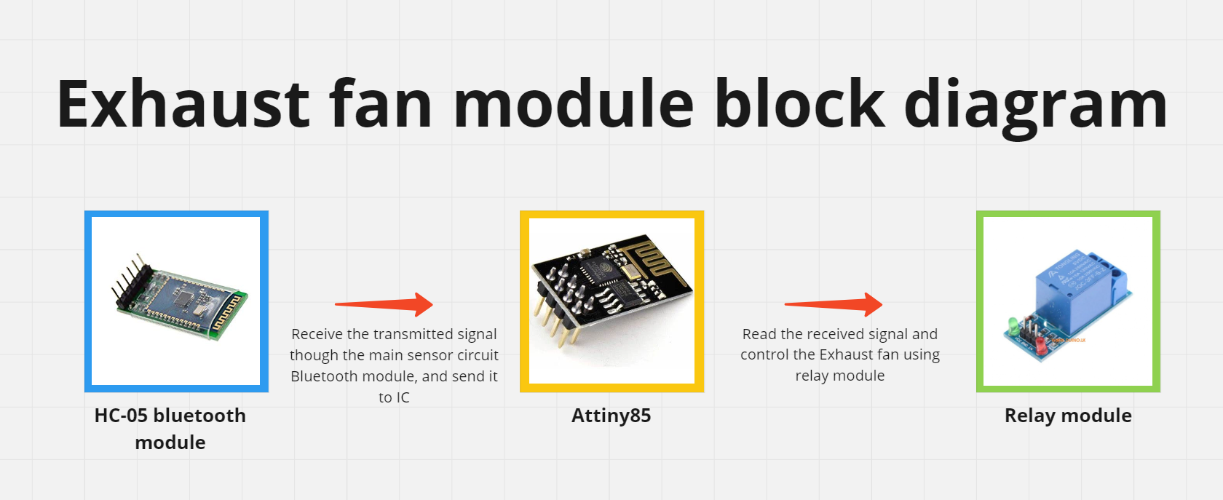
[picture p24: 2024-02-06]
Block diagram/Exhaust fan module block diagram.png

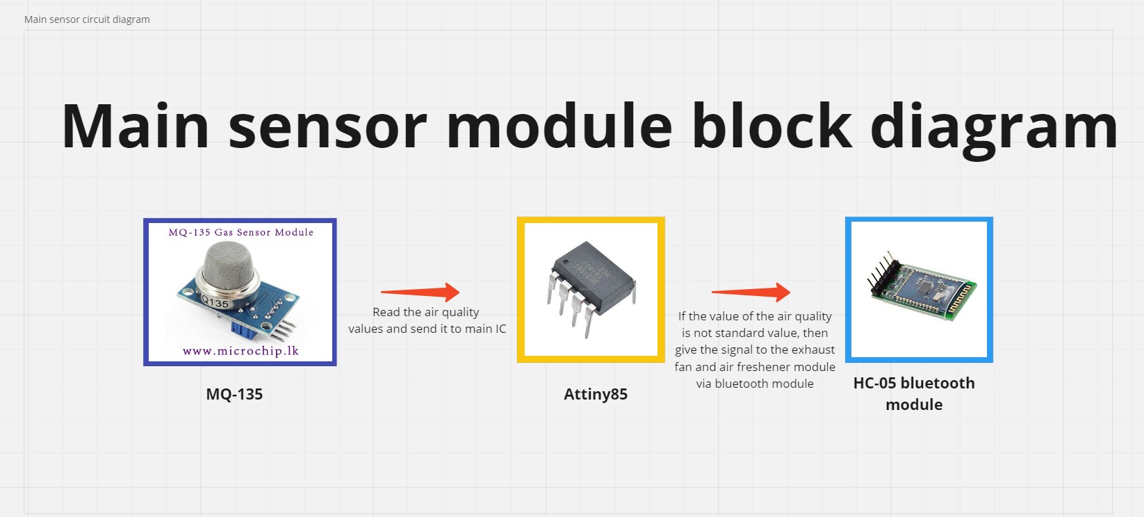
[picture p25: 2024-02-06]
Block diagram/sensor module block diagram.jpg

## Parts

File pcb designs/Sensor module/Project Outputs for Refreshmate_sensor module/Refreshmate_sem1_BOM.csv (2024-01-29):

Comment | Description | Designator | Footprint | LibRef | Quantity | LCSC Part
0.33uF | Capacitor | C1 | CAPR5-4X5 | Cap2 | 1
0.1uF | Capacitor | C2 | CAPR5-4X5 | Cap2 | 1
100uf 25V | Capacitor | C3 | CAPR5-4X5 | Cap2 | 1
2200uf 16V | Capacitor | C4 | CAPR5-4X5 | Cap2 | 1
LED1 | Typical RED GaAs LED | D1 | LED-1 | LED1 | 1
Diode 1N4007 | 1 Amp General Purpose Rectifier | D2, D3 | DO-41 | Diode 1N4007 | 2
9V Battery | 2 Pin Terminal Block 5mm Pitch | J1 | HANDSON_KF301-2P | KF301-2P | 1
12V Battery | 2 Pin Terminal Block 5mm Pitch | J2 | HANDSON_KF301-2P | KF301-2P | 1
9V RELAY | RELAY POWER 10A 12VDC 1C PCB TYPE (JS1) 5PIN QIANJ | K1 | JQC3FT731Z12VDC | JQC-3F-_T73_-1Z-12VDC | 1
MQ135 | Header, 4-Pin | P1 | HDR1X4 | Header 4 | 1
HC-05 Bluetooth module | Header, 6-Pin | P2 | HDR1X6 | Header 6 | 1
Header 6 | Header, 6-Pin | P3 | HDR1X6 | Header 6 | 1
Res1 | Resistor | R1 | AXIAL-0.3 | Res1 | 1
ATTINY85-20PU | AVR AVR® ATtiny, Functional Safety (FuSa) Microcontroller IC 8-Bit 20MHz 8KB (4K x 16) FLASH 8-PDIP | U1 | DIP762W46P254L927H533Q8B | ATTINY85-20PU | 1 | C965497
L7809CV | Linear Voltage Regulator IC Positive Fixed 1 Output 1.5A TO-220 | U2 | TO255P1040X460X1968-3 | L7805CV | 1 | C8091
L7805CV | Linear Voltage Regulator IC Positive Fixed 1 Output 1.5A TO-220 | U3 | TO255P1040X460X1968-3 | L7805CV | 1 | C111887

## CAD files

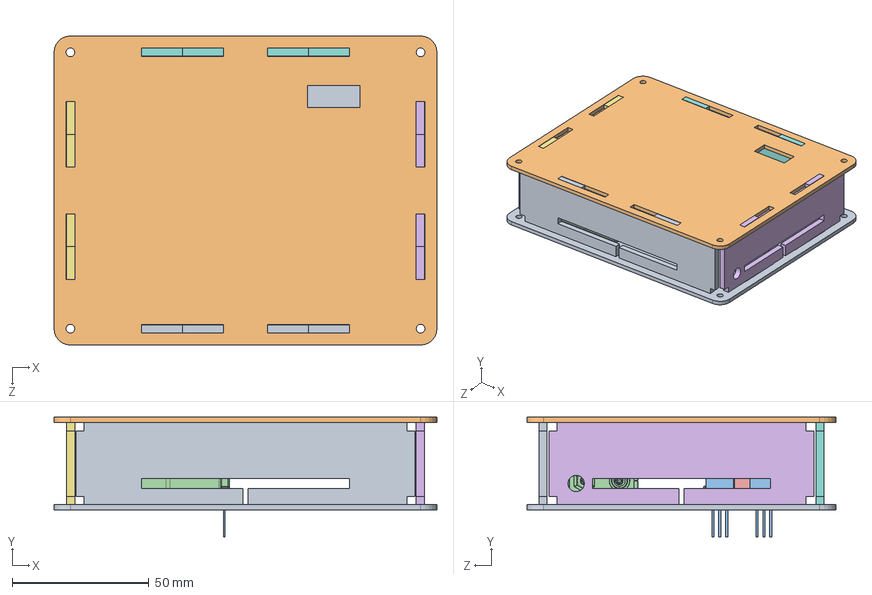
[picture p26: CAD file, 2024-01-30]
Solid works/Fan module/Refreshmate_fan_module_base_connector1 2 (1).SLDASM
140.0 x 43.8 x 113.0 mm
Refreshmate_relay_module_base
6320340160.step x 2
9V_Battery.step
Relay Module x 2
Refreshmate_relay_module_base_connector_thin_side
Refreshmate_relay_module_base_connector_thin_side - closetorelay
Refreshmate_relay_module_base_connector1
Refreshmate_relay_module_base_connector1 2
Refreshmate_relay_module_base - upside

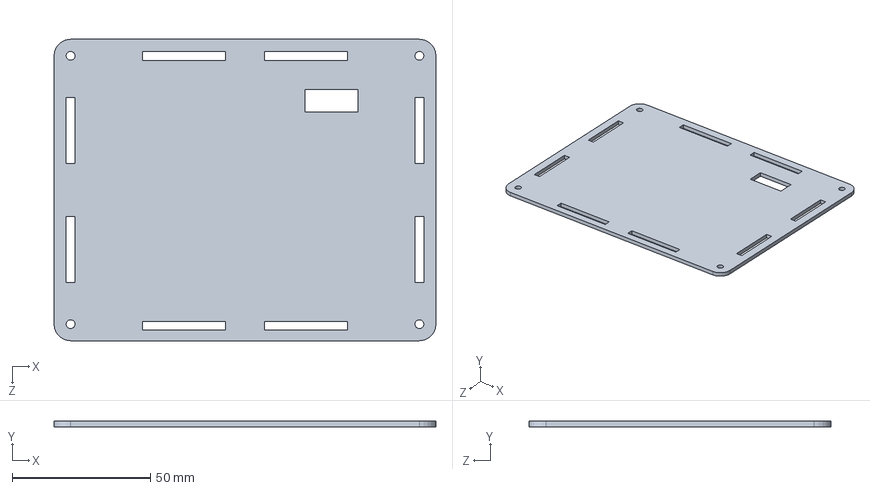
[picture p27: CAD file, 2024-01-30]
Solid works/Air freshner module/Refreshmate_airfreshner_module_base - upside.SLDPRT
138.1 x 2.00 x 109.0 mm

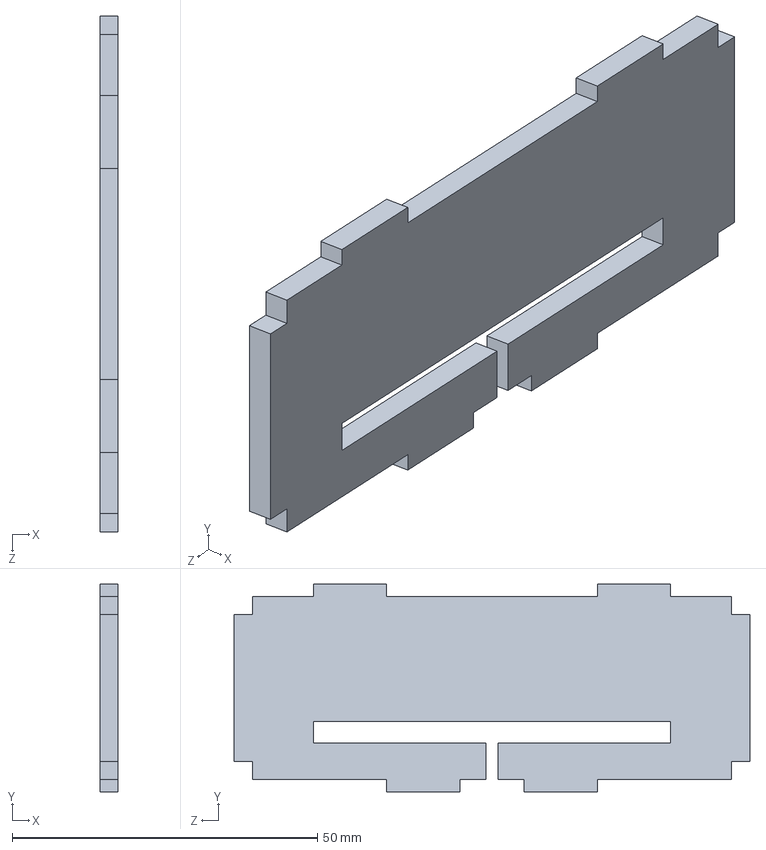
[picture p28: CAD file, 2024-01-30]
Solid works/Sensor module/Refreshmate_sensor_module_base_connector_thin_side.SLDPRT
3.00 x 34.0 x 84.5 mm

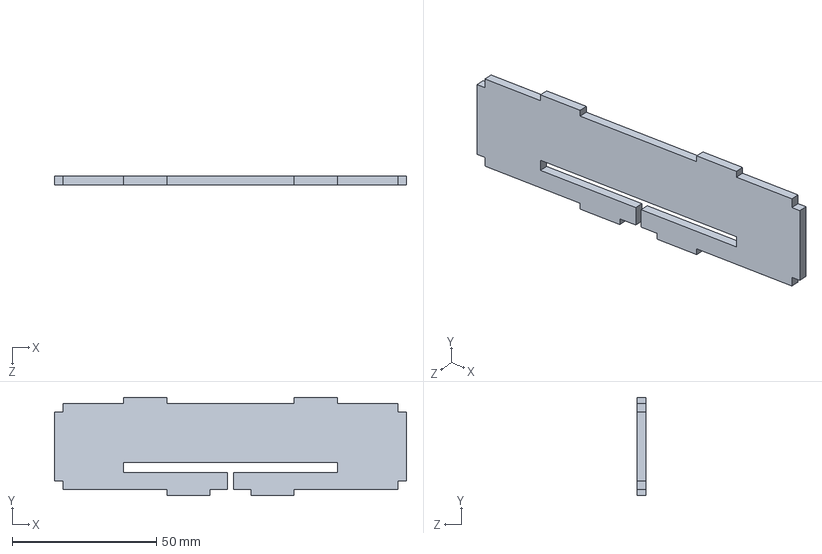
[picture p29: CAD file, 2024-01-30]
Solid works/Air freshner module/Refreshmate_airfreshner_module_base_connector12 .SLDPRT
122.1 x 34.0 x 3.00 mm

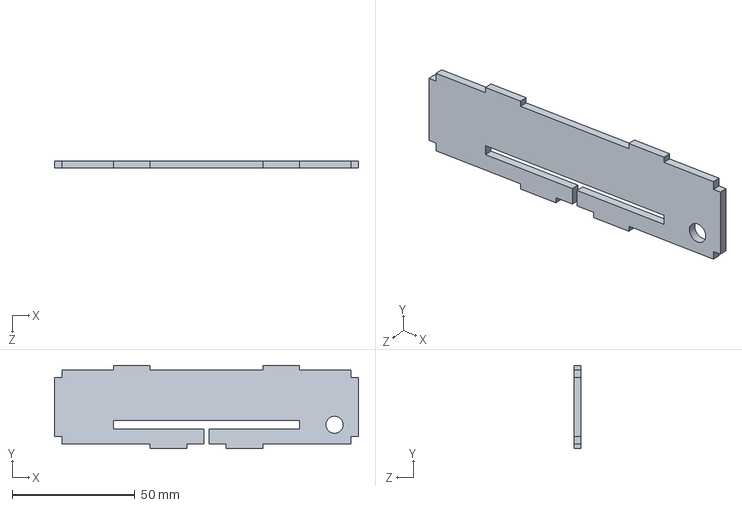
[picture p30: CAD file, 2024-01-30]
Solid works/Fan module/Refreshmate_fan_module_base_connector1 2 (2).SLDPRT
124.0 x 34.0 x 3.00 mm

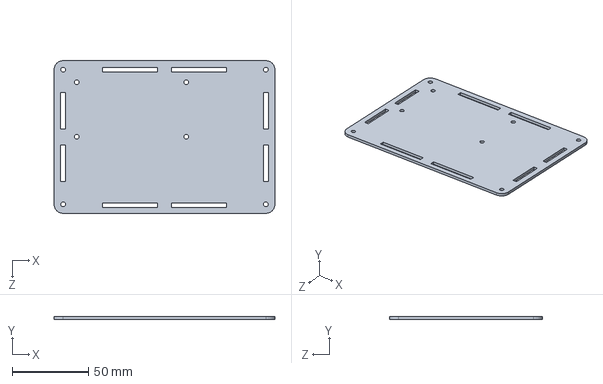
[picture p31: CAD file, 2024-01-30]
Solid works/Sensor module/Refreshmate_sensor_module_base.SLDPRT
145.3 x 2.00 x 100.5 mm

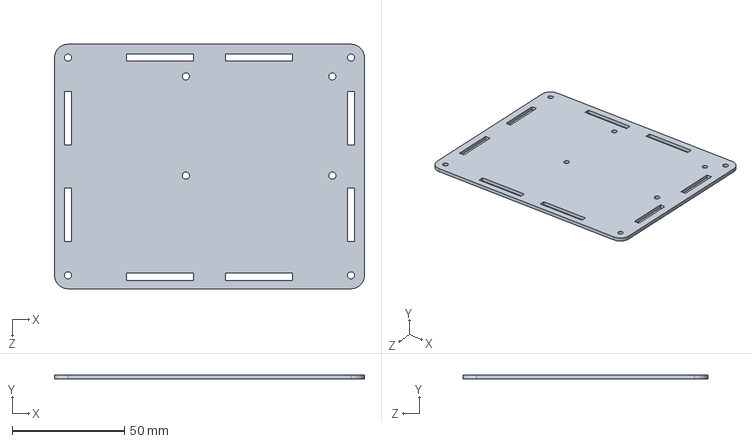
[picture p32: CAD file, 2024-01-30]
Solid works/Air freshner module/Refreshmate_airfreshner_module_base.SLDPRT
138.1 x 2.00 x 109.0 mm

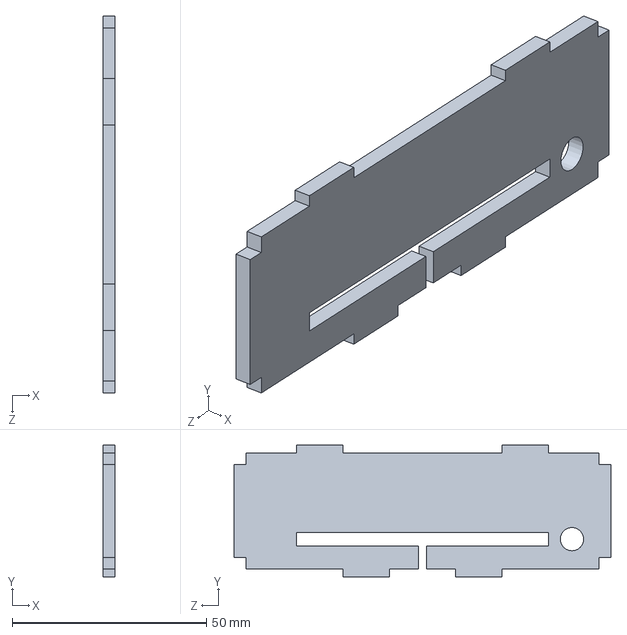
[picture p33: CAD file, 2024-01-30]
Solid works/Fan module/Refreshmate_fan_module_base_connector1 2 (6).SLDPRT
3.00 x 34.0 x 97.0 mm

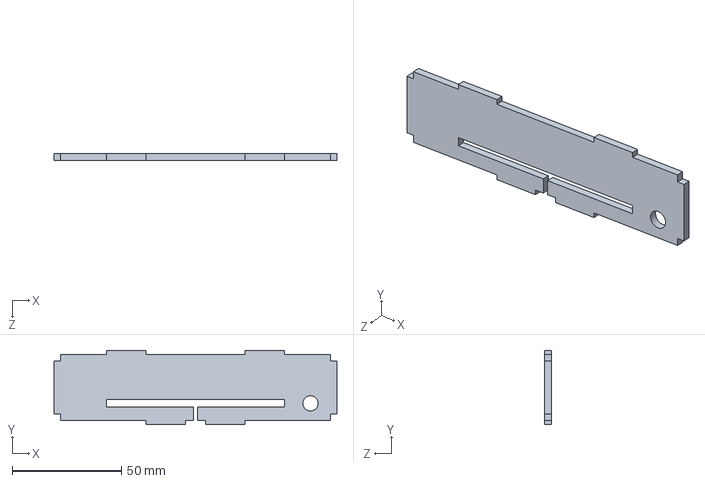
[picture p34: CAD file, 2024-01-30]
Solid works/Sensor module/Refreshmate_sensor_module_base_connector1.SLDPRT
129.3 x 34.0 x 3.00 mm

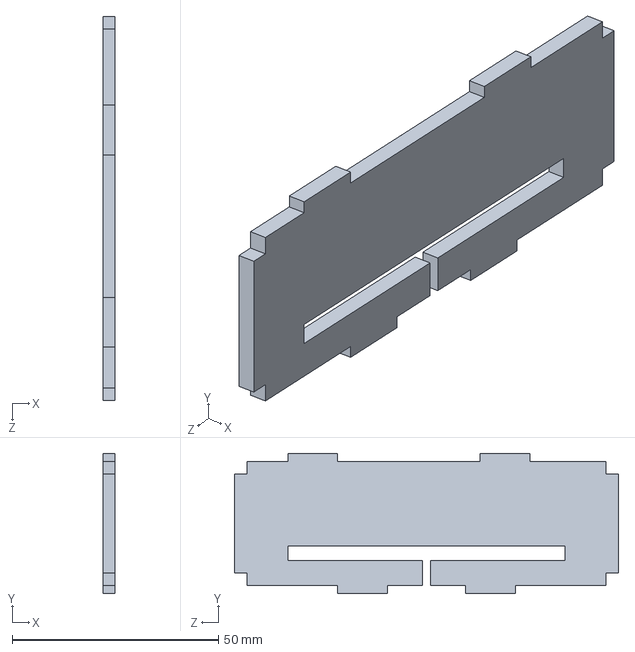
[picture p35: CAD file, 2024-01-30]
Solid works/Air freshner module/Refreshmate_airfreshner_module_base_connector_thin_side - connector.SLDPRT
3.00 x 34.0 x 93.0 mm

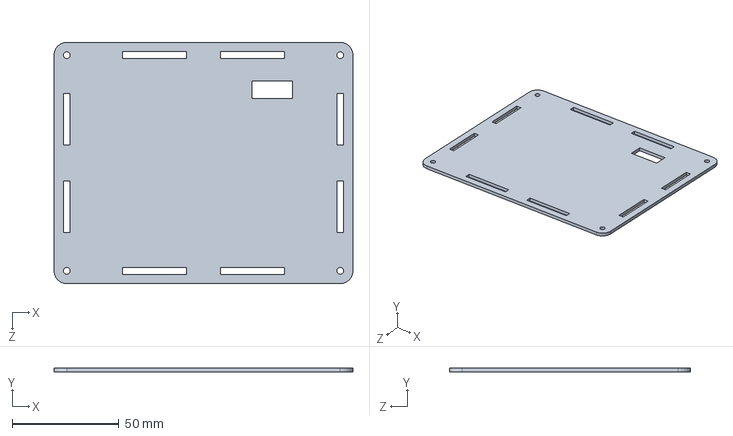
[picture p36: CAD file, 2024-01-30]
Solid works/Fan module/Refreshmate_fan_module_base_connector1 2 (3).SLDPRT
140.0 x 2.00 x 113.0 mm

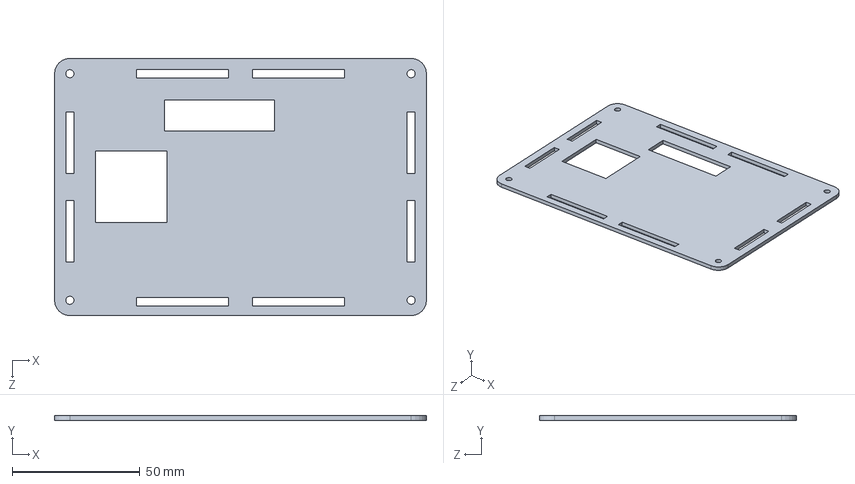
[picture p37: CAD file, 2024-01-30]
Solid works/Sensor module/Refreshmate_sensor_module_base - upside.SLDPRT
145.3 x 2.00 x 100.5 mm

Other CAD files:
Solid works/Sensor module/Refreshmate_sensor_module_base_connector12 .SLDPRT
Solid works/Air freshner module/Refreshmate_airfreshner_module_base_connector_thin_side.SLDPRT
Solid works/Fan module/Refreshmate_fan_module_base_connector1 2 (4).SLDPRT
Solid works/Air freshner module/Refreshmate_airfreshner_module_base_connector1.SLDPRT
Solid works/Fan module/Refreshmate_fan_module_base_connector1 2 (5).SLDPRT
Solid works/Fan module/Refreshmate_fan_module_base_connector1 2 (1).SLDPRT

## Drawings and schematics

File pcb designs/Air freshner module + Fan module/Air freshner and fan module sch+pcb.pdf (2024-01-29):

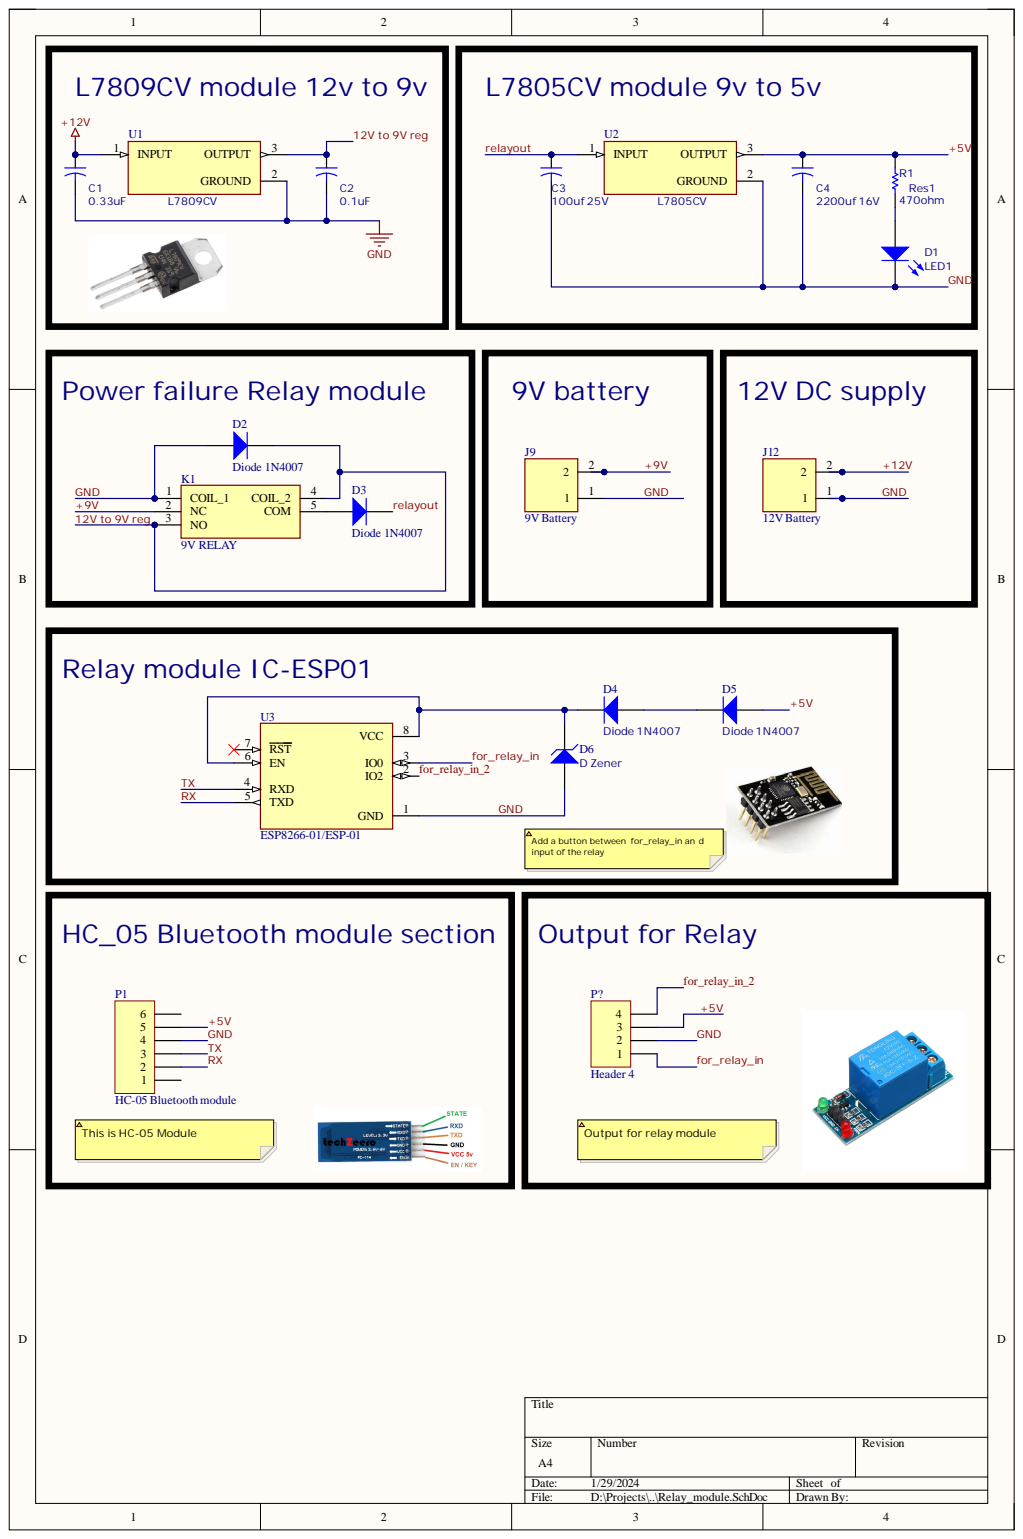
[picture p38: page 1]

Power failure Relay module

Add a button between for_relay_in and
input of the relay

Size A4 | Number | Revision

Date: 1/29/2024 | Sheet of
File: D:\Projects\..\Relay_module.SchDoc | Drawn By:

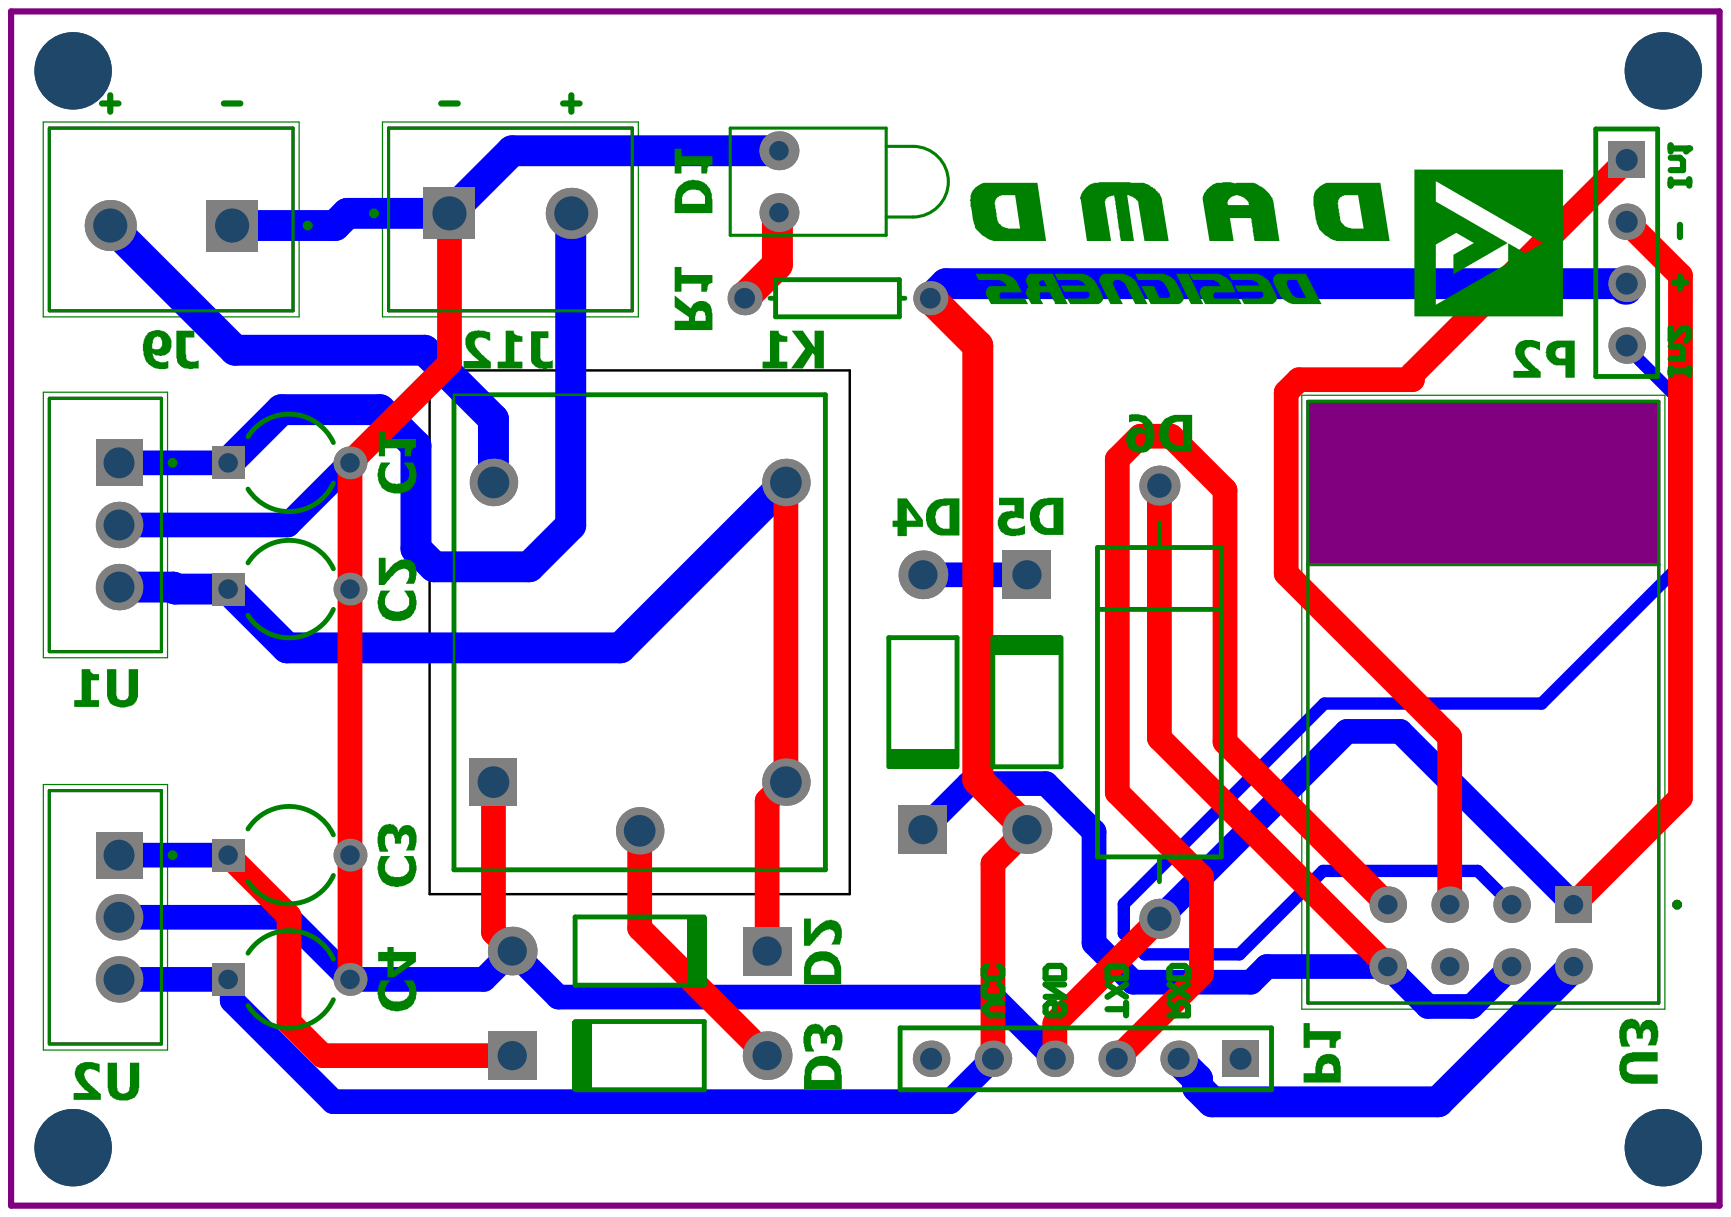
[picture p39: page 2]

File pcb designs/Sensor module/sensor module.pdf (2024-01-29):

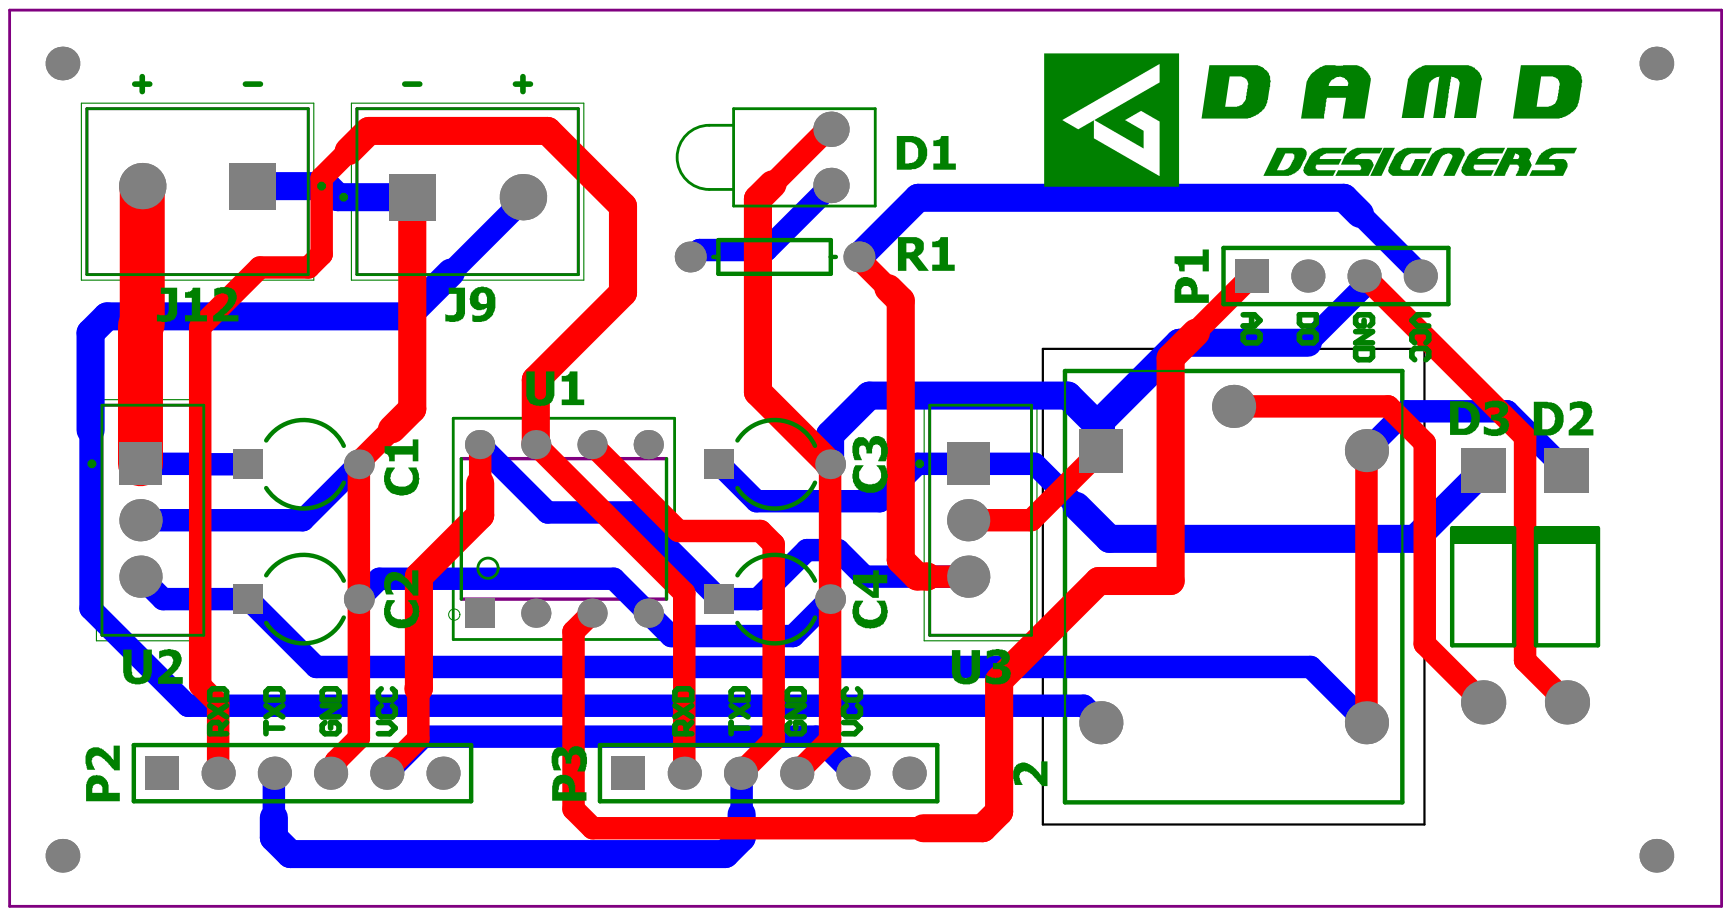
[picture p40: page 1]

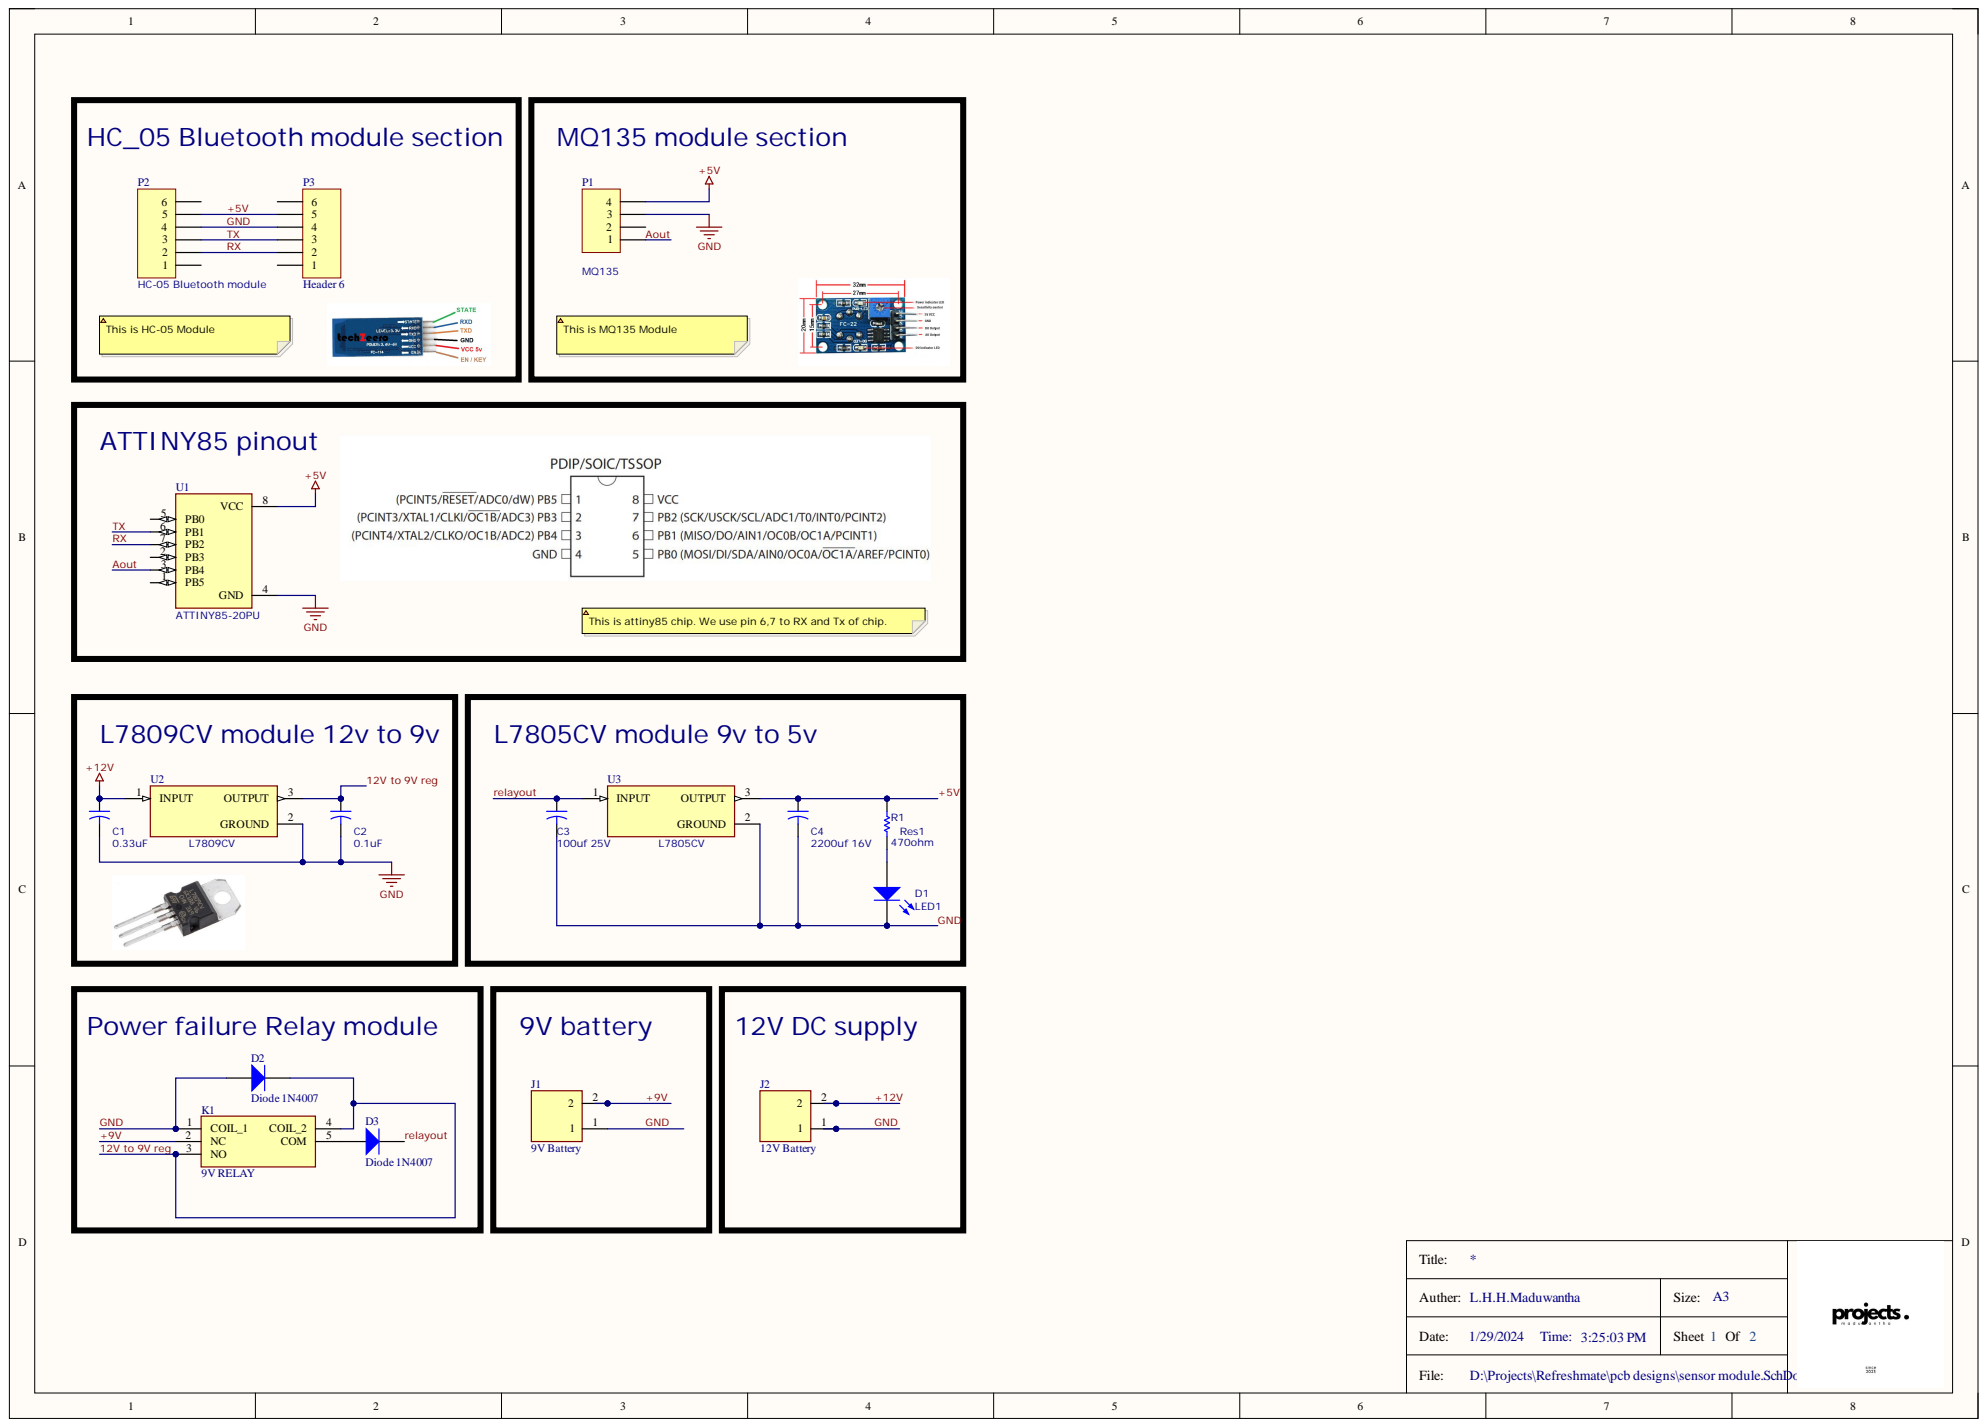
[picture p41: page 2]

This is attiny85 chip. We use pin 6,7 to RX and Tx of chip.

Power failure Relay module

Auther: L.H.H.Maduwantha | Size: A3

Date: 1/29/2024 Time: 3:25:03 PM | Sheet 1 Of 2

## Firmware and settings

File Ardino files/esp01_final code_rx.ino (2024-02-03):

char incomingValue = 0;

#define in1 0 // Pin 0

void setup() {
  // put your setup code here, to run once:
  Serial.begin(38400);
  pinMode(in1, OUTPUT);
}

void loop() {
  // put your main code here, to run repeatedly:
  if (Serial.available() > 0) {
    incomingValue = Serial.read();

    if (incomingValue == 'A') {
      digitalWrite(in1, HIGH);
      Serial.println(incomingValue);
      // delay(1000);
    } else if (incomingValue == 'B') {
      digitalWrite(in1, LOW);
      Serial.println(incomingValue);
      // delay(1000);
    }
  }

  Serial.println(1);
  delay(1000);
}

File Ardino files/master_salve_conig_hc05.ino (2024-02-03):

#include <SoftwareSerial.h>

// Define SoftwareSerial instance for HC-05 communication
SoftwareSerial mySerial(12, 13); // RX, TX

void setup() {
  // Open serial communications for debugging
  Serial.begin(9600);
  while (!Serial) {
    // Wait for serial port to connect (needed for native USB port only)
  }

  // Set up the data rate for the SoftwareSerial port (HC-05)
  mySerial.begin(38400);
}

void loop() {
  // Forward data from HC-05 to Serial
  if (mySerial.available()) {
    Serial.write(mySerial.read());
  }

  // Forward data from Serial to HC-05
  if (Serial.available()) {
    mySerial.write(Serial.read());
  }
}

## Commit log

2024-01-29 Pcb designs
    In the RefreshMate product line, I have combined the sensor module with the fan module and air freshener module. This design choice allows us to use the same PCB for both the air freshener and fan mo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
    [Refreshmate_Air_freshner_&_fan_module.SchDoc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]
2024-01-30 Solid works
    I have designed three types of enclosures for a project that incorporates sensor modules, an air freshener module, and a fan module. I opted for acrylic material to allow users to have a clear unders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
    [Refreshmate_airfreshner_module_base - upside.SLDPRT, Refreshmate_airfreshner_module_base.SLDPRT, Refreshmate_airfreshner_module_base_connector1.SLDPRT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]
2024-02-03 Circuit & enclosure png
2024-02-03 Arduino files
    I am utilizing an Arduino Uno board for testing purposes. The ESP01 module is employed in the air freshener and fan modules, while the ATtiny88 IC is utilized in the sensor module.
